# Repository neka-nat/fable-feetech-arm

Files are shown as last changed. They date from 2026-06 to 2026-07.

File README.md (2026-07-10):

# 6-Axis Robot Arm (Feetech STS3215 × 6)

`STS3215_03a.step`(Feetech STS3215 サーボ)を6個使った6軸ロボットアームのCADモデルです。
ブラケットの取り付けインターフェースはすべて STEP モデルから実測した寸法に合わせてあります。

## 生成方法

```bash
uv run python robot_arm.py                            # 直立姿勢で出力
uv run python robot_arm.py --pose "0,-40,70,30,50,0"  # J1..J6 [deg] を指定
```

出力:
- `robot_arm.step` — 指定ポーズの全体アセンブリ(サーボ6 + ブラケット7、部品ラベル・色付き)
- `out/parts/*.step` — ブラケット単品(3Dプリント用、ポーズ非依存)
- 実行時にペアワイズ干渉チェックを行い、重なりがあれば報告します(`--no-check` でスキップ)

## 3Dビューアでジョイントを動かす

ブラウザ上のスライダーで6軸をリアルタイムに動かせます(VS Code不要):

```bash
uv run python arm_viewer_viser.py
```

http://127.0.0.1:8080 をブラウザで開くと、右上のJ1〜J6スライダーで関節を
動かせます。メッシュは起動時に一度だけテッセレートし(初回は ~1分)、以後は
関節フレームの回転のみ更新するので操作はリアルタイムに反映されます。
`reset pose` ボタンで全関節を0(直立姿勢)に戻せます。

干渉チェックは行わないので、当たりが疑わしいポーズは `robot_arm.py --pose` で
確認してください(ペアワイズ干渉チェック付き)。

Pythonからは `from robot_arm import build_arm` で任意ポーズの
アセンブリ(`Compound`)を取得できます。

## 軸構成(ゼロ姿勢 = 直立)

| 軸 | 種別 | 軸方向 | 駆動部品 | 可動範囲(干渉チェック実測) |
|----|---|---|---|---|
| J1 | ベースヨー | Z | `base` → `b1_shoulder_mount` | ±180°(配線次第) |
| J2 | ショルダーピッチ | Y | `b1` → `b2_upper_arm`(リンク長 110 mm) | ±95° |
| J3 | エルボーピッチ | Y | `b2` → `b3_forearm` | −25°〜+95° |
| J4 | リストロール | Z | `b3` → `b4_wrist_mount` | ±180°(配線次第) |
| J5 | リストピッチ | Y | `b4` → `b5_wrist_link` | ±95° |
| J6 | ツールロール | Z | `b5` → `b6_tool_flange` | ±180°(配線次第) |

全高(直立時)約 371 mm、ショルダーからフランジまでの実効リーチ約 277 mm。
ピッチ軸の ±95° はコネクタプラグの掃引域回避、J3 の −25° は折返し方向で
J4サーボがアッパーアームのウェブに当たる限界です。制御側でリミットを設定してください。

## サーボとの取り合い(STEPから実測)

- **ドライブホイール**: Ø20、面 z=+18.7、Ø2.5 の4穴(9.9 mm 角配置)→ **M3 ねじ**(穴はM3タップ下径)。
  中心ねじ頭(z=+20.2 まで突出)用に Ø9.5 の逃がし座繰りを各ブラケットに設けています。
- **アイドラホイール**: Ø20、面 z=−17.7、同一穴パターン。中心ボス Ø6(z=−18.3)用の Ø7 逃がし付き。
  U字ブラケットはホイール/アイドラ両面を掴む両持ち支持です。
- **上面タブ**: 面 z=+15.9、Ø1.5 下穴 ×4(−29.0/−8.3, ±10.25)→ **M2 タッピングねじ**(皿、面一)。
- **下面タブ**: 面 z=−15.9、Ø1.5 下穴 ×4(−32.8/−8.3, ±10.25、上面と非対称)。
  アッパーアーム(b2)先端はコネクタ窓と共存させるため後方の2本のみ使用します。
- **コネクタ**: 底面後部のベイに 3ピンヘッダ ×2(ピンØ2、真下向き、先端 z=−19.4)。
  プラグは真下から挿抜し、プラグ本体はサーボ底面から z≈−26.5 まで張り出します。
  各ブラケットはこの空間と、関節回転で掃引する円環域を逃がしてあります。
- **干渉回避**: ケース上面リブ(z=+17.0 まで)・コネクタベイにはクランプ板・パッドに逃がし窓/溝をカット。

## プリント公差(v2 で追加)

実機フィードバック(嵌合がきつい)を受けて、以下の嵌合クリアランスを入れています。

- ホイール/アイドラを掴むボス当たり面: **片側 0.35 mm**(M3 を締めると密着)
- タブクランプ面(クランプ板・パッド・ベースデッキ): **片側 0.2 mm**
- ホイール/アイドラ貫通穴: Ø23.6 / Ø24.0(斜め入れ込み組立を考慮)

## ハーネス取り回し(v2 で追加)

- **ベース**: 底板にサーボ挿入兼用の大開口があり、サーボ1は**下から**挿入します。
  プラグも下から挿し、ケーブルは底面の溝(深さ4 mm、後縁 −X 側へ)を通して外に出します。
  背面壁のスロットは手アクセス・予備の引き出し口です。J1→J2 のケーブルはベース外側を
  立ち上げ、J1 回転のたるみ(サービスループ)を確保してください。
- **アッパーアーム(b2)**: 肘側サーボ(J3)のコネクタはアイドラ側プレートの**貫通窓**から
  外側に挿抜します。ケーブルはアーム外側底面を這わせ、途中のタイラップ穴(Ø3.5×2組)で
  固定して肩側へ送ります。
- **肩・手首クランプ(b1/b4)**: クランプ板Bの窓からプラグが横に抜けます。
- **デッキ上のサーボ(J4・J6)**: コネクタ挿抜スペースがデッキ裏側で狭いため、
  **ケーブルを挿してからデッキに固定**してください。

## ねじBOM(目安)

| 用途 | ねじ | 数量 |
|---|---|---|
| ホイール/アイドラ固定 | M3×6 キャップ/ボタン | 4×9箇所 = 36 |
| サーボタブ固定 | M2×8〜10 皿タッピング | 34 |
| ベース固定 | M4×12 + 座繰り | 4 |

## 組立・運用ノート

- ホイール用 M3 はスラブ/フランジに設けた Ø6 のドライバーアクセス穴から締めます。
  デッキ上のサーボ(J4・J6)はタブねじを締めてから次のブラケットを取り付けてください。
- U字ブラケットへのサーボ入れ込みは、ホイール側を先に穴へ掛けてから斜めに倒し込みます。
  b2 先端(J3)はリブ溝・ベイ溝に沿わせてスライドさせると入ります。
- 可動範囲は軸構成の表を参照(J3 の折返し側 −25° に注意)。
- ブラケット推奨: PETG/PLA、壁4周・インフィル40%以上。プレート厚は基本4 mm、
  タブクランプ板はホイール面との段差制約(2.8 mm)から 2.5 mm。

https://github.com/user-attachments/assets/94f7e1a7-6c1c-4f5c-9313-85d68564109c

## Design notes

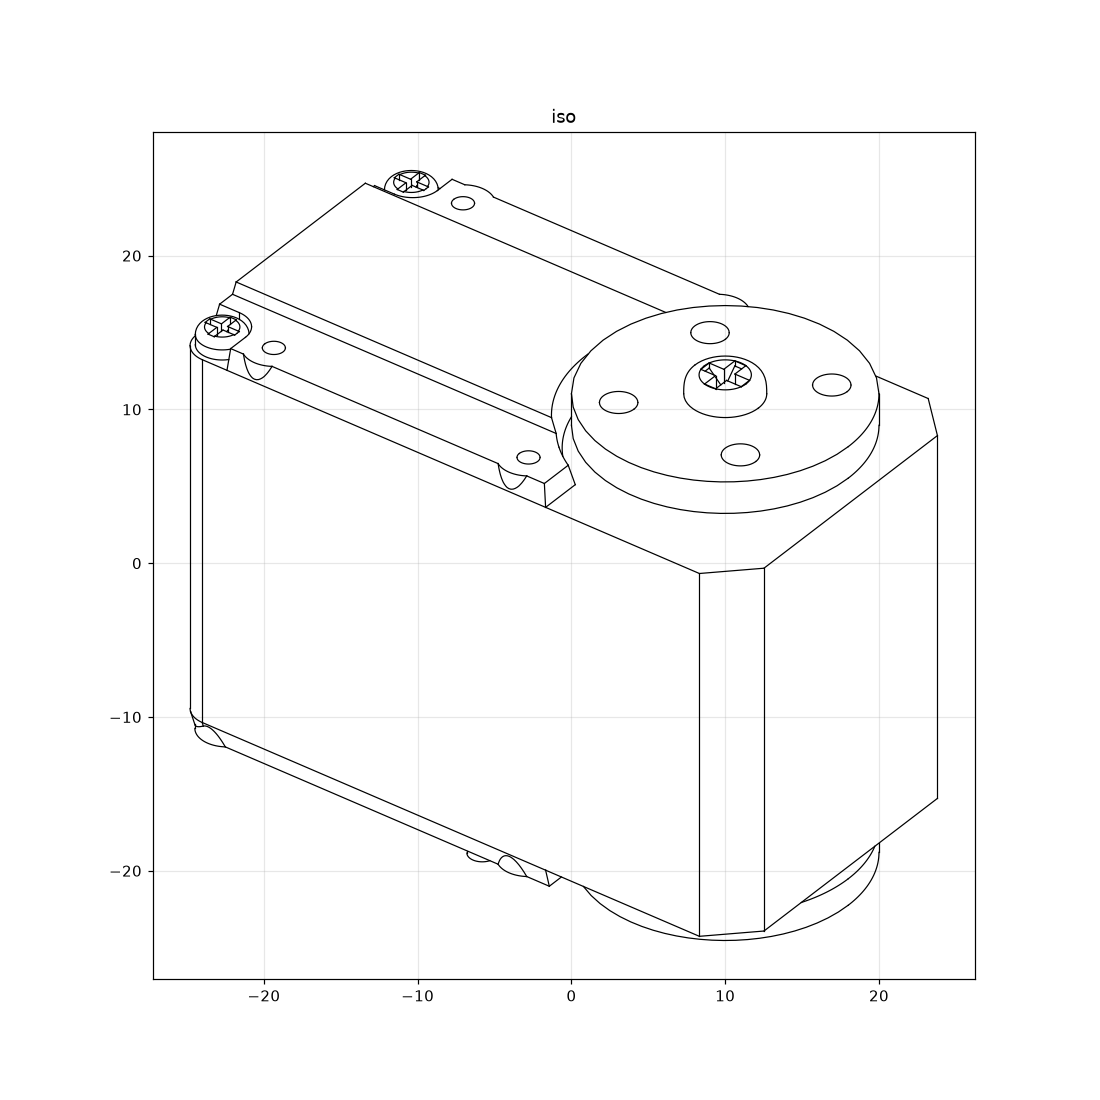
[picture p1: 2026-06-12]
out/servo_iso.png

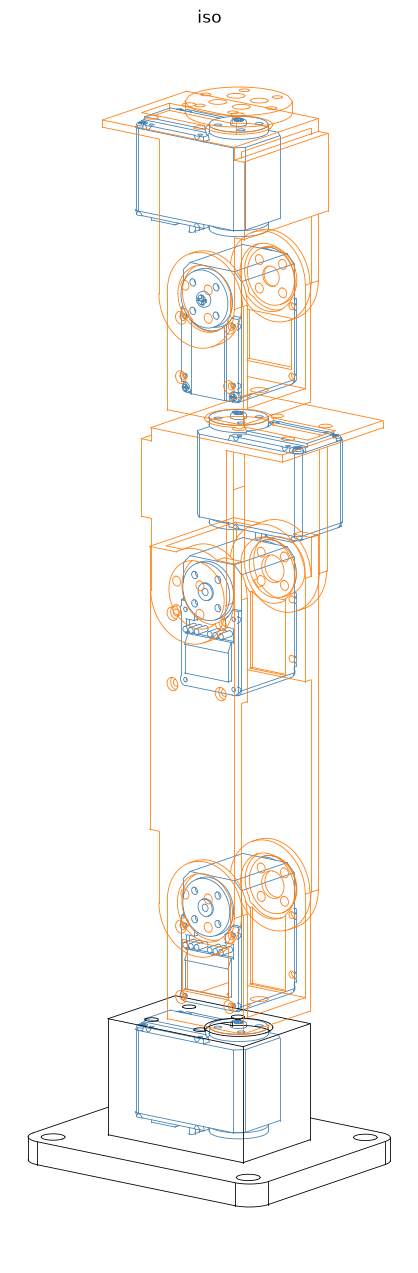
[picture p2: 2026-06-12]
out/arm_iso.png

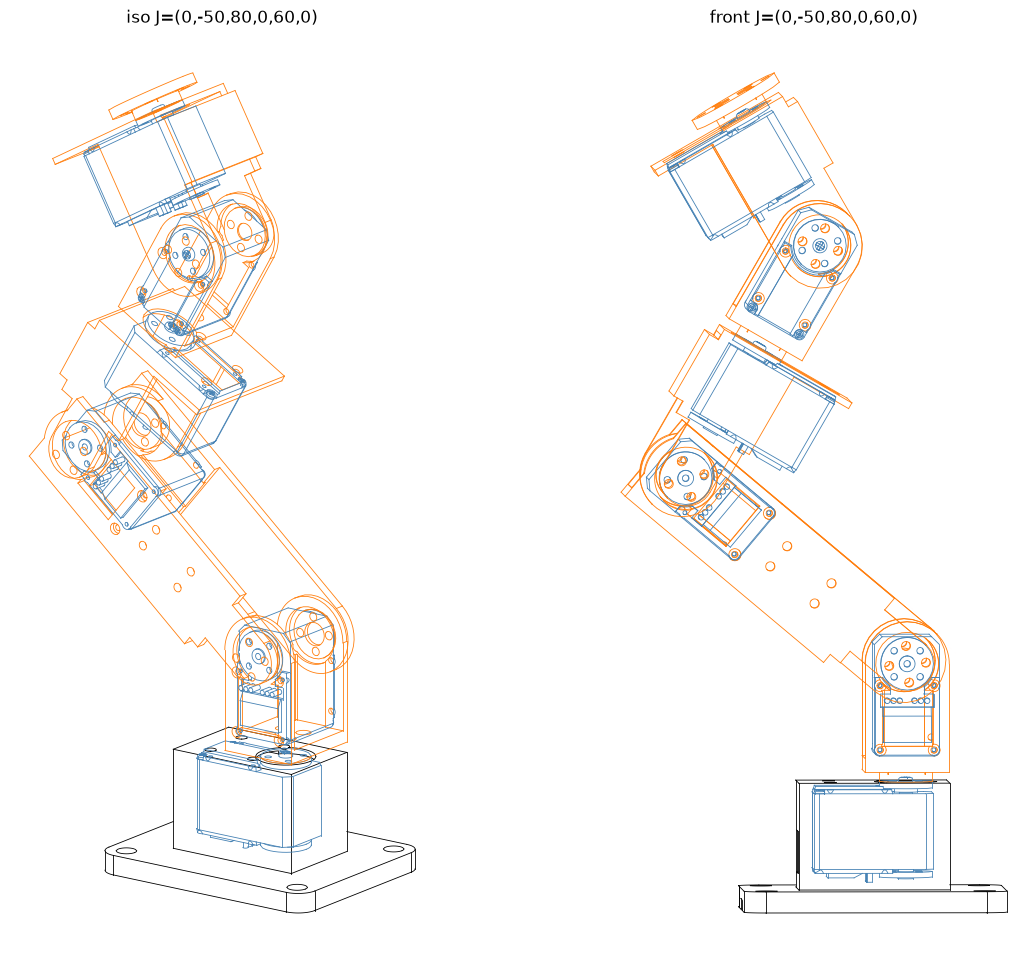
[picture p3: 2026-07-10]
out/rev2_arm.png

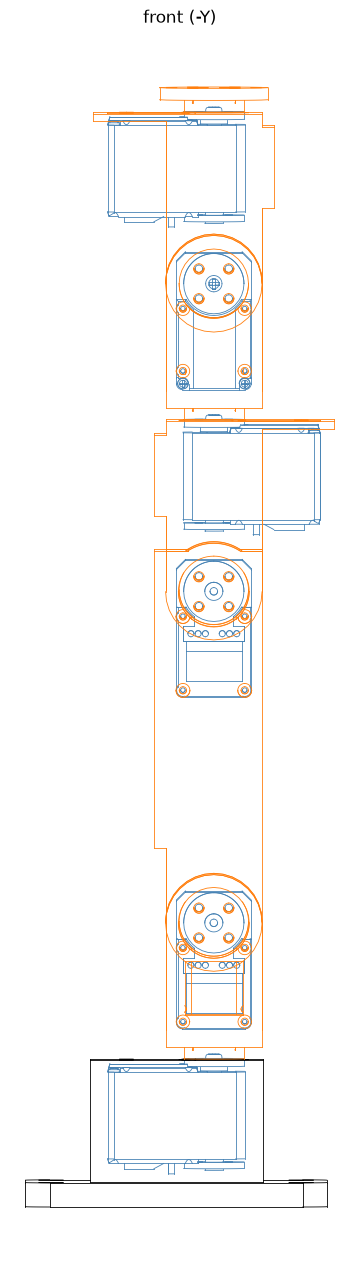
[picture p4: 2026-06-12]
out/arm_front.png

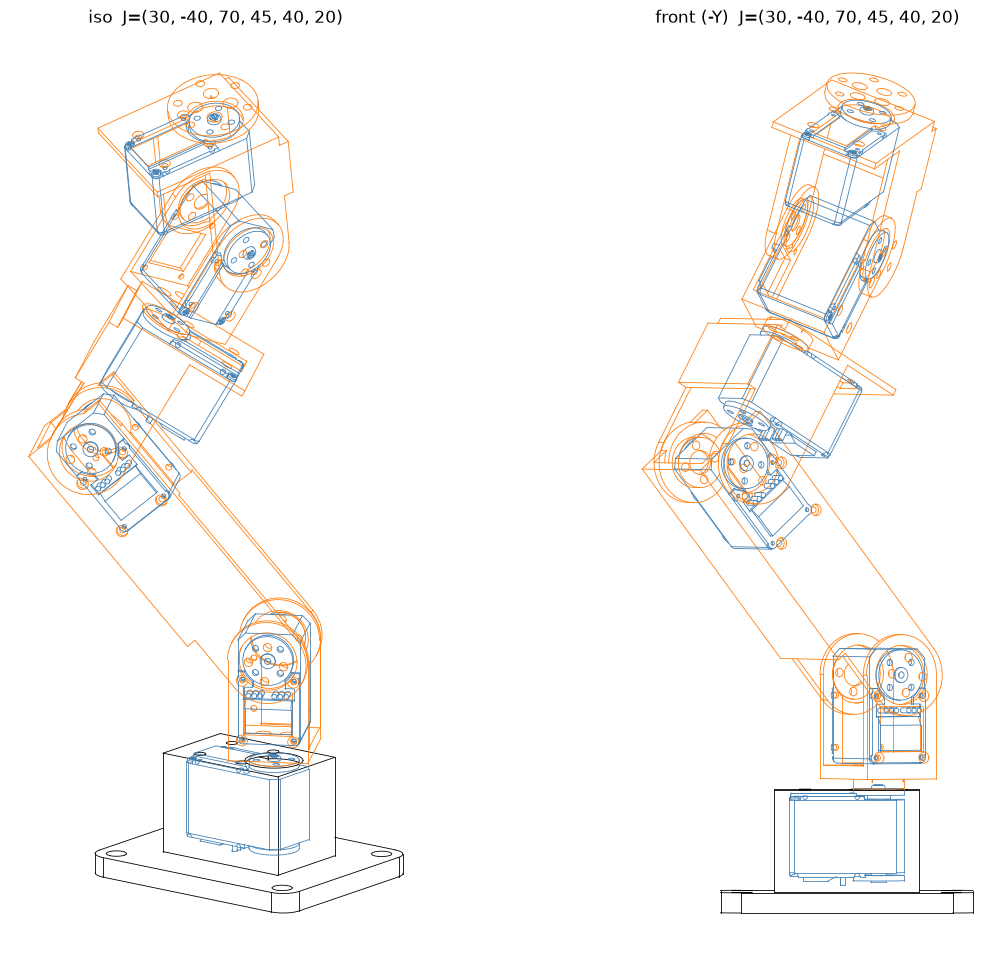
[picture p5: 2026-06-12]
out/pose_preview.png

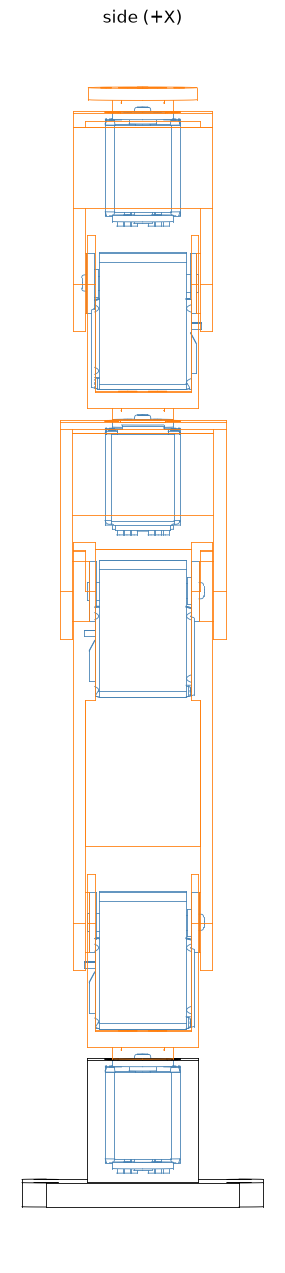
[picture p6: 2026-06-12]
out/arm_side.png

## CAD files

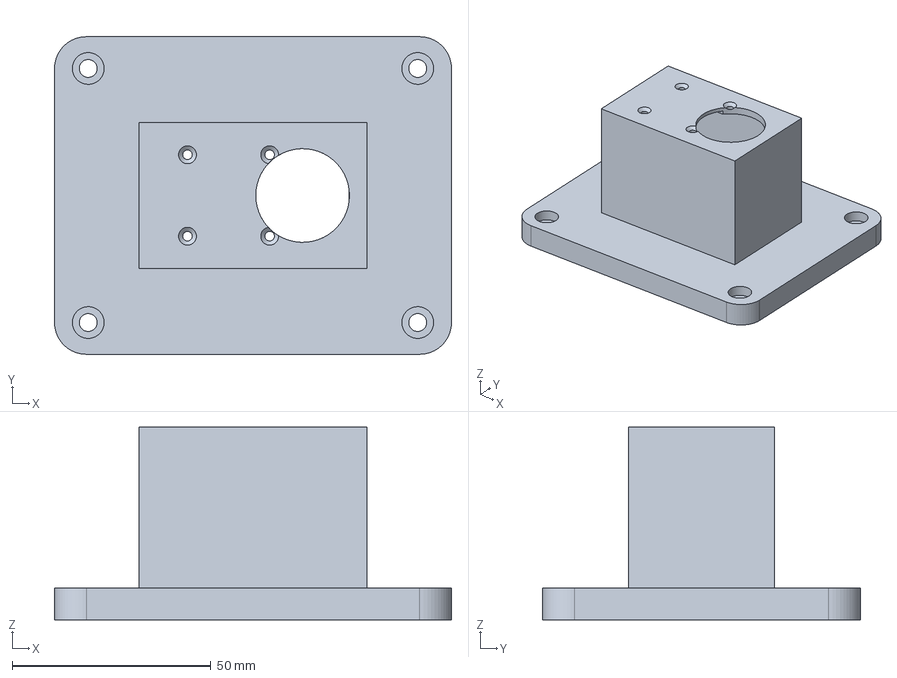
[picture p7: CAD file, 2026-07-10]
out/parts/base.step
100.0 x 80.0 x 48.6 mm

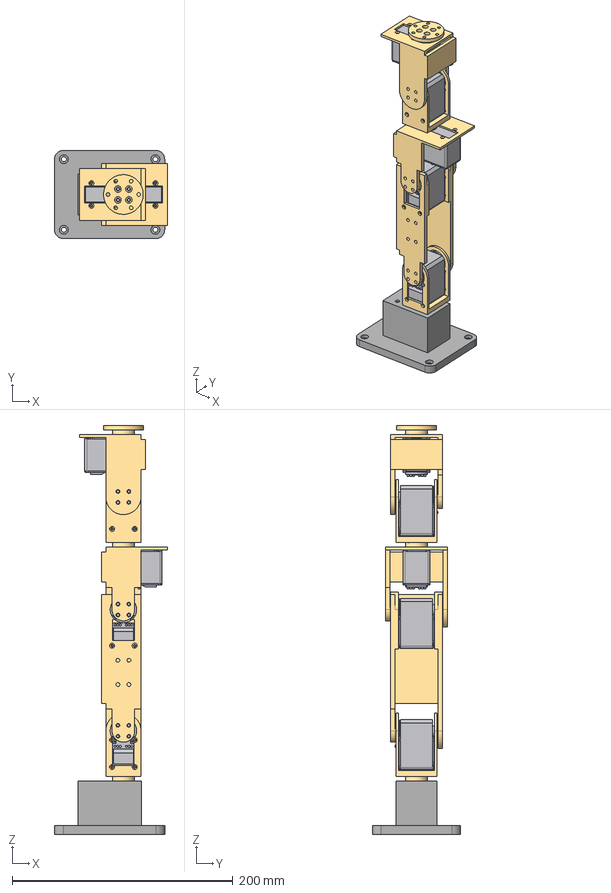
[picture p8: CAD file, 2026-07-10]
robot_arm.step
102.5 x 80.0 x 370.9 mm
base
servo_6_STS3215 x 6
b1_shoulder_mount
b2_upper_arm
b3_forearm
b4_wrist_mount
b5_wrist_link
b6_tool_flange

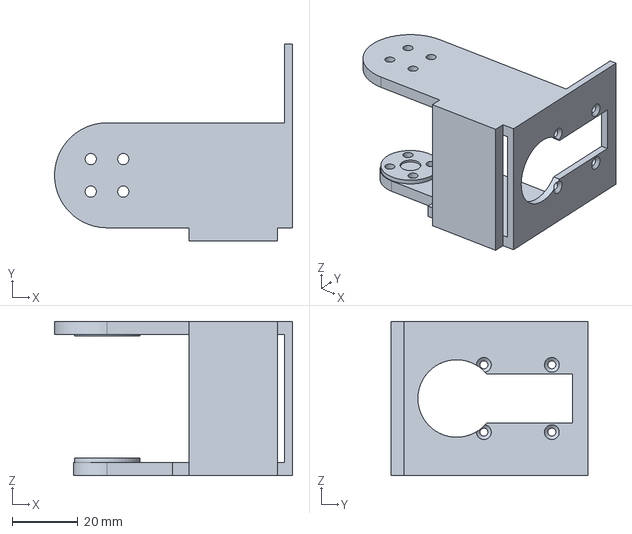
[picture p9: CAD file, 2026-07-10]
out/parts/b5_wrist_link.step
72.5 x 60.0 x 47.0 mm

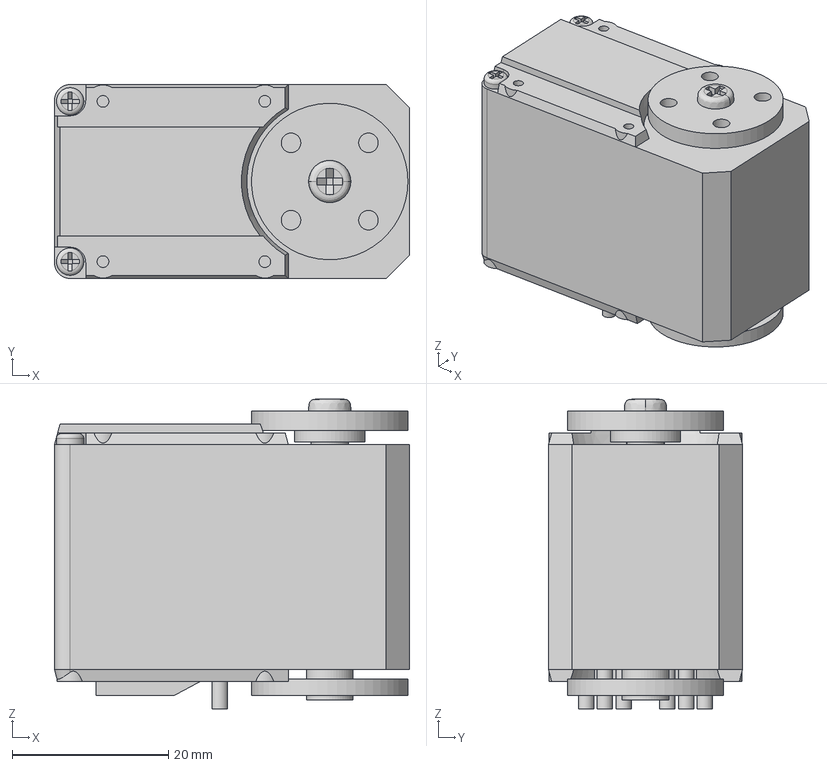
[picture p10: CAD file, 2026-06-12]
STS3215_03a.step
45.4 x 24.8 x 39.6 mm

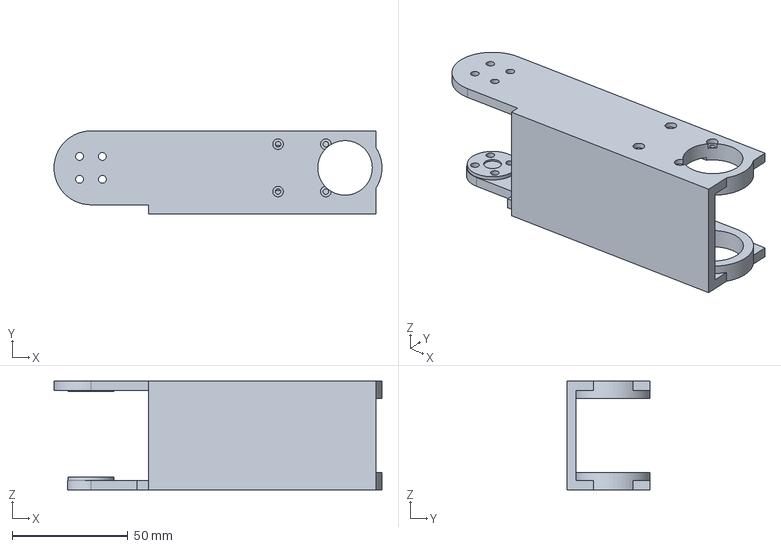
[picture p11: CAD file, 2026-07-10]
out/parts/b2_upper_arm.step
142.0 x 36.0 x 47.0 mm

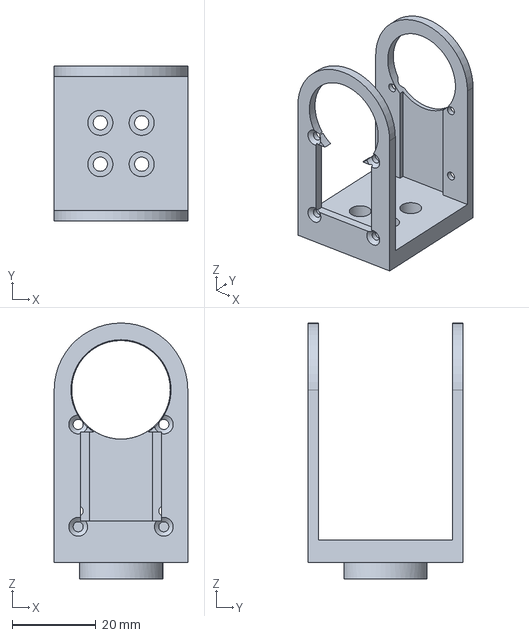
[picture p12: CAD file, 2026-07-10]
out/parts/b4_wrist_mount.step
32.0 x 37.2 x 61.3 mm

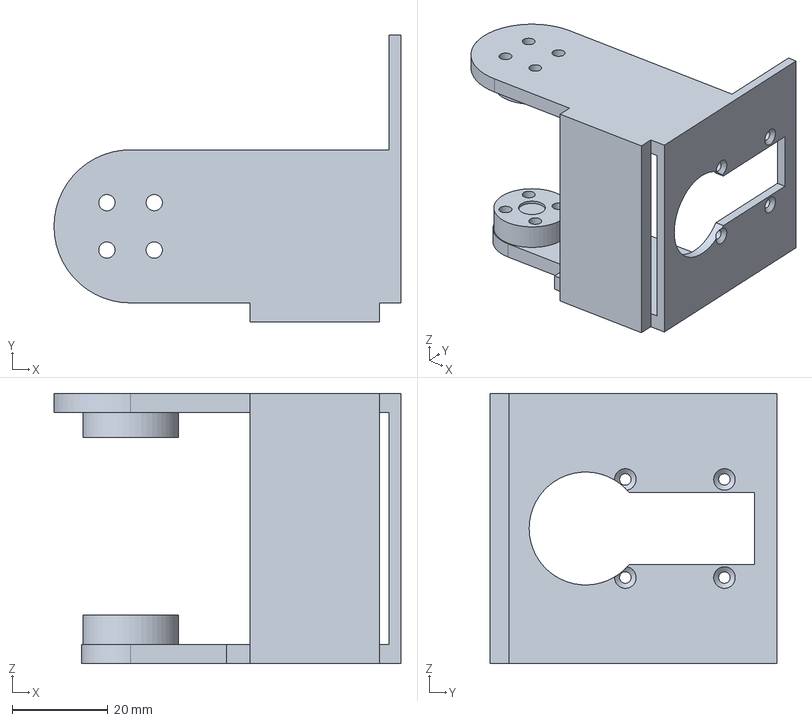
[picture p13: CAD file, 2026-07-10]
out/parts/b3_forearm.step
72.5 x 60.0 x 56.5 mm

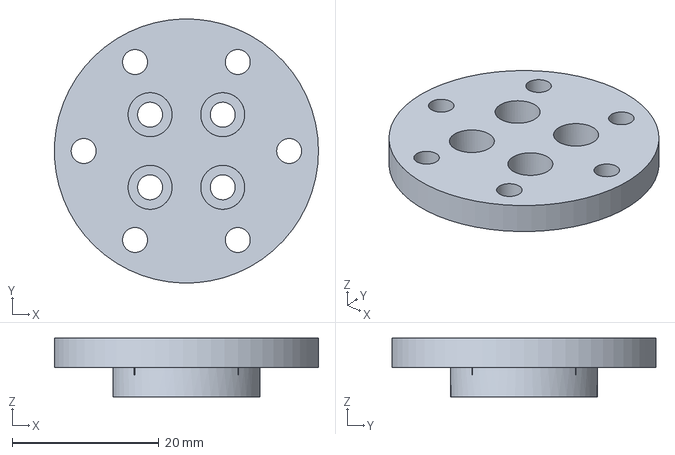
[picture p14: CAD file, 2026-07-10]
out/parts/b6_tool_flange.step
36.0 x 36.0 x 8.00 mm

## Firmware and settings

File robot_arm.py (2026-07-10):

"""6-axis robot arm built around the Feetech STS3215 servo (STS3215_03a.step).

All bracket interfaces are derived from dimensions measured directly on the
imported STEP model.  Servo local frame used below ("axis frame"):
  - origin on the output axis (STEP model shifted by x -= 12.5)
  - +Z along the output axis toward the drive wheel

Measured servo geometry (axis frame, mm):
  drive wheel  : Ø20 disc, face z=+18.7, 4 x Ø2.5 (M3 tap) on a 9.9 mm square
  center screw : head Ø~5.4 protruding to z=+20.2
  idler wheel  : Ø20 disc, face z=-17.7, same hole pattern,
                 center boss Ø6 protruding to z=-18.3
  top tabs     : surface z=+15.9, Ø1.5 pilot holes (M2 self-tapping) at
                 (-29.0, ±10.25) and (-8.3, ±10.25)
  bottom tabs  : surface z=-15.9, holes at (-32.8, ±10.25) and (-8.3, ±10.25)
  body         : x in [-35.2, 10.2], y ±12.4, case z ±14.4
  top ridge    : x in [-34.78, -8.51], y ±7.0, protrudes to z=+17.0
  connector bay: block x in [-29.9, -16.6], y ±9.2, bottom z=-17.7.
                 Two 3-pin headers, pins Ø2 pointing straight down (-Z) at
                 x [-15.05, -13.05], y ±2.8/±5.2/±7.6, tips z=-19.4.
                 Mated plugs slide on from below: plug bodies occupy about
                 x [-17, -11], y ±9.5, down to z ~ -26.5, wires exiting
                 further down/backward.  Brackets must keep this volume --
                 and the annulus it sweeps around the joint -- clear.
"""

import copy
from build123d import *

MM = 1.0

# ---------------------------------------------------------------- measured --
WHEEL_FACE = 18.7
IDLER_FACE = -17.7
TAB_TOP = 15.9
TAB_BOT = -15.9
WHEEL_R = 10.0
SCREW_HEAD_TOP = 20.2  # wheel center screw head
IDLER_BOSS_BOT = -18.3

HORN_HOLES = [(4.95, 4.95), (4.95, -4.95), (-4.95, 4.95), (-4.95, -4.95)]
TOP_TABS = [(-29.0, 10.25), (-29.0, -10.25), (-8.3, 10.25), (-8.3, -10.25)]
BOT_TABS = [(-32.8, 10.25), (-32.8, -10.25), (-8.3, 10.25), (-8.3, -10.25)]

BODY_X0, BODY_X1 = -35.2, 10.2
BODY_Y = 12.4
RIDGE_X0, RIDGE_X1 = -34.78, -8.51
CONN_X0, CONN_X1 = -29.9, -13.05

# ------------------------------------------------------------- clearances --
M3_CLEAR = 3.4 / 2          # wheel screws (servo holes are M3 tap size Ø2.5)
M2_CLEAR = 2.4 / 2          # tab screws (M2 self tapping into Ø1.5 pilots)
WHEEL_HOLE_R = 23.6 / 2     # bracket clearance hole around wheel/idler
IDLER_HOLE_R = 24.0 / 2
HEAD_RECESS_R = 9.5 / 2     # recess over the wheel center screw head
BOSS_RECESS_R = 7.0 / 2     # recess over the idler center boss
ACCESS_R = 6.0 / 2          # screwdriver access holes for M3 wheel screws

FIT_AX = 0.35               # print fit: gap per side, wheel/idler grip bosses
FIT_TAB = 0.2               # print fit: gap per side, tab clamp faces

PLATE_T = 4.0               # structural plate thickness
CLAMP_T = 2.5               # tab clamp plate thickness (limited by wheel face)
NARROW = 19.5               # U-bracket inner face when gripping a bare servo
WIDE = 24.25                # ... when gripping a servo held by U-link pads

CLAMP_DZ = 64.0             # axis offset gripped servo -> clamped servo
DECK_L = 54.0               # u_link length when ending in a roll-servo deck
ARM_L = 110.0               # shoulder->elbow link length
BASE_H = 30.0               # base servo axis frame height over base plate top


def box(x0, x1, y0, y1, z0, z1):
    return Pos((x0 + x1) / 2, (y0 + y1) / 2, (z0 + z1) / 2) * Box(
        abs(x1 - x0), abs(y1 - y0), abs(z1 - z0)
    )


def cyl_z(r, z0, z1, x=0.0, y=0.0):
    return Pos(x, y, (z0 + z1) / 2) * Cylinder(r, abs(z1 - z0))


def cyl_y(r, y0, y1, x=0.0, z=0.0):
    return Pos(x, (y0 + y1) / 2, z) * Rot(90, 0, 0) * Cylinder(r, abs(y1 - y0))


def cyl_x(r, x0, x1, y=0.0, z=0.0):
    return Pos((x0 + x1) / 2, y, z) * Rot(0, 90, 0) * Cylinder(r, abs(x1 - x0))


def csk_z(x, y, z_surf, up=True):
    """M2 countersink opening at the plane z=z_surf (head toward +z if up)."""
    s = 1 if up else -1
    hole = cyl_z(M2_CLEAR, z_surf - s * 12, z_surf + s * 2, x, y)
    cone = Pos(x, y, z_surf - s * 0.5) * Rot(0 if up else 180, 0, 0) * Cone(
        bottom_radius=1.2, top_radius=2.3, height=1.1
    )
    return hole + cone


def csk_x(y, z, x_surf, toward_pos_x=True):
    s = 1 if toward_pos_x else -1
    hole = cyl_x(M2_CLEAR, x_surf - s * 12, x_surf + s * 2, y, z)
    cone = Pos(x_surf - s * 0.5, y, z) * Rot(0, 90 if toward_pos_x else -90, 0) * Cone(
        bottom_radius=1.2, top_radius=2.3, height=1.1
    )
    return hole + cone


def csk_y(x, z, y_surf, toward_pos_y=True):
    s = 1 if toward_pos_y else -1
    hole = cyl_y(M2_CLEAR, y_surf - s * 12, y_surf + s * 2, x, z)
    cone = Pos(x, y_surf - s * 0.5, z) * Rot(-90 if toward_pos_y else 90, 0, 0) * Cone(
        bottom_radius=1.2, top_radius=2.3, height=1.1
    )
    return hole + cone


# ------------------------------------------------------------------ parts --
def horn_disc(access_holes=False):
    """Ø20 disc bolted onto the drive wheel (built on the gripped servo)."""
    p = cyl_z(WHEEL_R, WHEEL_FACE, WHEEL_FACE + PLATE_T)
    p -= cyl_z(HEAD_RECESS_R, WHEEL_FACE - 0.1, SCREW_HEAD_TOP + 0.3)
    for hx, hy in HORN_HOLES:
        p -= cyl_z(M3_CLEAR, WHEEL_FACE - 1, WHEEL_FACE + PLATE_T + 1, hx, hy)
    return p


def clamp_mount():
    """B1/B4: horn disc + floor slab + twin plates clamping the next servo.

    Built in the *gripped* servo's axis frame.  The clamped servo sits at
    Pos(0,0,CLAMP_DZ) with its axis along +Y (local), tail pointing down.
    """
    zc = CLAMP_DZ
    tabf = TAB_TOP + FIT_TAB                   # clamp faces sit FIT_TAB clear
    disc_top = WHEEL_FACE + PLATE_T            # 22.7
    slab_top = disc_top + 5.3                  # 28.0
    p = horn_disc()
    p += box(-16, 16, -(tabf + CLAMP_T), tabf + CLAMP_T, disc_top, slab_top)
    for hx, hy in HORN_HOLES:                  # M3 driver access through slab
        p -= cyl_z(ACCESS_R, disc_top - 1, slab_top + 1, hx, hy)

    # plate A (+y): clamps the next servo's top tabs, wheel pokes through
    pa = box(-16, 16, tabf, tabf + CLAMP_T, disc_top + 0.1, zc)
    pa += cyl_y(16, tabf, tabf + CLAMP_T, x=0, z=zc)
    pa -= cyl_y(WHEEL_HOLE_R, tabf - 1, tabf + CLAMP_T + 1, x=0, z=zc)
    pa -= box(-7.5, 7.5, tabf - 1, TAB_TOP + 1.45,  # case top ridge window
              zc + RIDGE_X0 - 1.5, zc + RIDGE_X1 + 1.5)
    for tx, ty in TOP_TABS:
        pa -= csk_y(x=ty, z=zc + tx, y_surf=tabf + CLAMP_T, toward_pos_y=True)

    # plate B (-y): clamps bottom tabs; idler pokes through.  The connector
    # window passes the mated plugs (they exit down-forward past the plate).
    pb = box(-16, 16, -tabf - CLAMP_T, -tabf, disc_top + 0.1, zc)
    pb += cyl_y(16, -tabf - CLAMP_T, -tabf, x=0, z=zc)
    pb -= cyl_y(IDLER_HOLE_R, -tabf - CLAMP_T - 1, -tabf + 1, x=0, z=zc)
    pb -= box(-9.7, 9.7, -tabf - CLAMP_T - 1, -TAB_TOP + 1,  # connector bay
              zc + CONN_X0 - 1.5, zc + CONN_X1 + 3.0)
    for tx, ty in BOT_TABS:
        pb -= csk_y(x=ty, z=zc + tx, y_surf=-tabf - CLAMP_T, toward_pos_y=False)

    return p + pa + pb


def u_link(length, inner, end):
    """U-bracket gripping wheel+idler of a servo, built in its axis frame.

    The link runs along local +X.  end='pads' clamps the next servo (same
    orientation, axis at Pos(length,0,0)) between internal pads; end='deck'
    carries a deck plate at x=length holding the next servo with its output
    axis along local +X (tail toward +y).
    """
    outer = inner + PLATE_T
    tabf = TAB_TOP + FIT_TAB
    x_end = length + (13.5 if end == "pads" else 2.5)

    def side_plate(s):  # s=+1 wheel side, s=-1 idler side
        if s > 0:
            pl = box(0, x_end, -16, 16, s * inner, s * outer)
            pl += cyl_z(16, s * inner, s * outer)
        else:
            # the gripped servo's mated plugs hang straight down over the
            # pins (r ~11..19 from the axis, down to z ~ -26.5).  Keep the
            # joint disc r10.25 and the first 22 mm of plate only 20.5 mm
            # wide so the rotating link sweeps past the plugs (~±95 deg).
            pl = box(0, 22, -10.25, 10.25, s * inner, s * outer)
            pl += box(20, x_end, -16, 16, s * inner, s * outer)
            pl += cyl_z(10.25, s * inner, s * outer)
        if end == "pads":
            pl += cyl_z(16, s * inner, s * outer, x=length)
        # contact boss FIT_AX short of the wheel / idler face; the M3 screws
        # pull it snug, and assembly gets 2*FIT_AX of insertion clearance
        if s > 0:
            pl += cyl_z(WHEEL_R, WHEEL_FACE + FIT_AX, inner + 0.1)
            pl -= cyl_z(HEAD_RECESS_R, WHEEL_FACE - 0.1,
                        SCREW_HEAD_TOP + 0.3 + FIT_AX)
        else:
            pl += cyl_z(WHEEL_R, -inner - 0.1, IDLER_FACE - FIT_AX)
            pl -= cyl_z(BOSS_RECESS_R, IDLER_FACE + 0.1,
                        IDLER_BOSS_BOT - 0.1 - FIT_AX)
        for hx, hy in HORN_HOLES:
            pl -= cyl_z(M3_CLEAR, s * (WHEEL_FACE - 2), s * (outer + 1), hx, hy)
        return pl

    # back web (-y side) first: it touches both side plates, keeping the
    # accumulated result a single connected solid
    web_x1 = x_end if end == "pads" else length - 2
    p = box(25, web_x1, -20, -16, -outer, outer)
    p += side_plate(+1)
    p += side_plate(-1)

    if end == "pads":
        # bottom tabs: only the tail pair -- the front pair would sit inside
        # the connector exit window cut below
        for s, hole_r, tabs in (
            (+1, WHEEL_HOLE_R, TOP_TABS),
            (-1, IDLER_HOLE_R, [t for t in BOT_TABS if t[0] < -30]),
        ):
            pad = box(length - 36, length, -16, 16, s * tabf, s * inner)
            pad += cyl_z(16, s * tabf, s * inner, x=length)
            p += pad
            p -= cyl_z(hole_r, s * (tabf - 1), s * (outer + 1), x=length)
            if s > 0:  # case top ridge groove along the whole pad (insertion)
                p -= box(length - 37, length + RIDGE_X1 + 1.5,
                         -7.5, 7.5, tabf - 1, TAB_TOP + 1.45)
            else:
                # connector bay groove along the whole pad (insertion) ...
                p -= box(length - 37, length + CONN_X1 + 1.0,
                         -9.7, 9.7, -tabf + 1, -inner - 1.4)
                # ... and a window through the side plate so the plugs can be
                # mated from outside and the wires exit below the link
                p -= box(length - 28.2, length - 9, -10, 10,
                         -inner + 0.1, -outer - 1)
            for tx, ty in tabs:
                hole = cyl_z(M2_CLEAR, s * (TAB_TOP - 2), s * (outer + 1),
                             length + tx, ty)
                cb = cyl_z(2.3, s * (outer - 2.0), s * (outer + 1),
                           length + tx, ty)  # counterbore, head flush
                p -= hole + cb
        if length > 80:  # zip-tie holes to dress the wires along the outside
            for zx in (42, 64):
                for zy in (-5, 5):
                    p -= cyl_z(1.75, -inner + 0.1, -outer - 1, zx, zy)
    else:  # deck
        deck = box(length, length + 2.5, -16, 40, -outer, outer)
        deck -= cyl_x(WHEEL_HOLE_R, length - 1, length + 3.5, y=0, z=0)
        deck -= box(length - 1, length + 3.5, 8.0, 35.3, -7.5, 7.5)  # ridge
        for ny, nz in ((29.0, 10.25), (29.0, -10.25), (8.3, 10.25), (8.3, -10.25)):
            deck -= csk_x(y=ny, z=nz, x_surf=length + 2.5, toward_pos_x=True)
        p += deck
    return p


def base_part():
    """Base plate + box body + top deck clamping servo 1 vertically.

    The plate has a large opening under the servo: the servo is inserted
    from below (wheel up through the deck hole, tabs against the deck
    underside), and its mated plugs hang into the opening.  Wires leave
    through a groove milled in the plate underside toward the -x edge.
    """
    deck_z0 = BASE_H + TAB_TOP + FIT_TAB  # 46.1
    deck_z1 = deck_z0 + CLAMP_T           # 48.6
    p = box(-62.5, 37.5, -40, 40, 0, 8)   # base plate
    p = fillet(p.edges().filter_by(Axis.Z), 8)
    for bx, by in ((-54, -32), (-54, 32), (29, -32), (29, 32)):
        p -= cyl_z(2.25, -1, 9, bx, by)
        p -= cyl_z(4.0, 4.5, 9, bx, by)   # M4 head counterbore
    walls = box(-41.2, 16.2, -18.4, 18.4, 8, deck_z0)
    walls -= box(-37.2, 12.2, -14.4, 14.4, 7, deck_z0 + 1)
    walls -= box(-42.2, -36.2, -8, 8, 14, 30)   # rear hand/cable slot
    deck = box(-41.2, 16.2, -18.4, 18.4, deck_z0, deck_z1)
    deck -= cyl_z(WHEEL_HOLE_R, deck_z0 - 1, deck_z1 + 1)
    deck -= box(RIDGE_X0 - 1.5, RIDGE_X1 + 1.5, -7.5, 7.5,
                deck_z0 - 1, BASE_H + TAB_TOP + 1.45)
    for tx, ty in TOP_TABS:
        deck -= csk_z(tx, ty, deck_z1, up=True)
    p = p + walls + deck
    p -= box(-36.7, 11.7, -13.4, 13.4, -1, 9)   # servo/plug opening
    p -= box(-63.5, -20, -7, 7, -1, 4)          # underside cable groove
    return p


def flange_part():
    """Tool flange bolted to servo 6's wheel."""
    p = horn_disc()
    top0 = WHEEL_FACE + PLATE_T
    p += cyl_z(18, top0, top0 + PLATE_T)
    for i in range(6):
        a = i * 60
        p -= cyl_z(M3_CLEAR, top0 - 1, top0 + PLATE_T + 1,
                   14 * Vector(1, 0, 0).rotate(Axis.Z, a).X,
                   14 * Vector(1, 0, 0).rotate(Axis.Z, a).Y)
    for hx, hy in HORN_HOLES:  # M3 driver access
        p -= cyl_z(ACCESS_R, top0 - 1, top0 + PLATE_T + 1, hx, hy)
    return p


# ------------------------------------------------------------- kinematics --
servo_raw = import_step("STS3215_03a.step")
SHIFT = Location((-12.5, 0, 0))  # put output axis at the frame origin

L1 = Location((0, 0, BASE_H))
T_clamp = Plane(origin=(0, 0, CLAMP_DZ), x_dir=(0, 0, 1), z_dir=(0, 1, 0)).location
T_link = Location((ARM_L, 0, 0))
T_deck = Plane(origin=(DECK_L - TAB_TOP, 0, 0), x_dir=(0, -1, 0), z_dir=(1, 0, 0)).location

BRACKET_NAMES = [
    "b1_shoulder_mount", "b2_upper_arm", "b3_forearm",
    "b4_wrist_mount", "b5_wrist_link", "b6_tool_flange",
]
# transform from joint i's *driven* frame to servo i+1's frame
CHAIN = [T_clamp, T_link, T_deck, T_clamp, T_deck]

_brackets = None


def bracket_parts():
    """Unplaced bracket geometry (built once, cached)."""
    global _brackets
    if _brackets is None:
        _brackets = {
            "base": base_part(),
            "b1_shoulder_mount": clamp_mount(),
            "b2_upper_arm": u_link(ARM_L, NARROW, "pads"),
            "b3_forearm": u_link(DECK_L, WIDE, "deck"),
            "b4_wrist_mount": clamp_mount(),
            "b5_wrist_link": u_link(DECK_L, NARROW, "deck"),
            "b6_tool_flange": flange_part(),
        }
    return _brackets


def build_arm(angles=(0, 0, 0, 0, 0, 0)):
    """Assemble the arm at the given pose.

    angles: J1..J6 in degrees.  Each joint rotates about the output axis
    (local +Z) of its servo; all zero = the arm pointing straight up.
    Returns a Compound whose children are the 6 servos and 7 brackets.
    """
    br = bracket_parts()
    parts = []

    base = br["base"].moved(Location())
    base.label, base.color = "base", Color(0.15, 0.15, 0.15)
    parts.append(base)

    loc = L1  # servo 1 frame
    for i in range(6):
        s = copy.copy(servo_raw).moved(loc * SHIFT)
        s.label = f"servo_{i + 1}_STS3215"
        s.color = Color(0.25, 0.25, 0.28)
        parts.append(s)

        driven = loc * Rotation(0, 0, angles[i])  # joint i+1 motion
        b = br[BRACKET_NAMES[i]].moved(driven)
        b.label = BRACKET_NAMES[i]
        b.color = Color(0.95, 0.55, 0.10)
        parts.append(b)

        if i < 5:
            loc = driven * CHAIN[i]  # next servo rides on this bracket

    asm = Compound(children=parts)
    asm.label = "robot_arm_6dof_sts3215"
    return asm


def check_collisions(asm, tol=0.01, verbose=True):
    """Pairwise interference check; returns list of (label_a, label_b, mm3)."""
    parts = list(asm.children)
    hits = []
    for i in range(len(parts)):
        for j in range(i + 1, len(parts)):
            a, b = parts[i], parts[j]
            ba, bb = a.bounding_box(), b.bounding_box()
            if (ba.min.X > bb.max.X or bb.min.X > ba.max.X or
                    ba.min.Y > bb.max.Y or bb.min.Y > ba.max.Y or
                    ba.min.Z > bb.max.Z or bb.min.Z > ba.max.Z):
                continue
            try:
                inter = a.intersect(b)
                if inter is None:
                    v = 0
                elif hasattr(inter, "volume"):
                    v = inter.volume
                else:  # ShapeList: several disjoint intersection lumps
                    v = sum(s.volume for s in inter)
            except Exception as e:
                if verbose:
                    print(f"  WARN {a.label} x {b.label}: intersect failed ({e})")
                v = 0
            if v > tol:
                hits.append((a.label, b.label, v))
                if verbose:
                    print(f"  OVERLAP {a.label} x {b.label}: {v:.2f} mm^3")
    if verbose and not hits:
        print("  no overlaps")
    return hits


if __name__ == "__main__":
    import argparse
    import os

    ap = argparse.ArgumentParser(description=__doc__)
    ap.add_argument("--pose", default="0,0,0,0,0,0",
                    help="J1..J6 angles in degrees, comma separated")
    ap.add_argument("--no-check", action="store_true",
                    help="skip the pairwise interference check")
    args = ap.parse_args()
    pose = tuple(float(a) for a in args.pose.split(","))
    assert len(pose) == 6, "--pose needs 6 comma separated angles"

    asm = build_arm(pose)
    os.makedirs("out/parts", exist_ok=True)
    export_step(asm, "robot_arm.step")
    for name, p in bracket_parts().items():
        export_step(p, f"out/parts/{name}.step")
    print(f"exported robot_arm.step (pose {pose}) and out/parts/*.step")

    if not args.no_check:
        print("collision check:")
        check_collisions(asm)
